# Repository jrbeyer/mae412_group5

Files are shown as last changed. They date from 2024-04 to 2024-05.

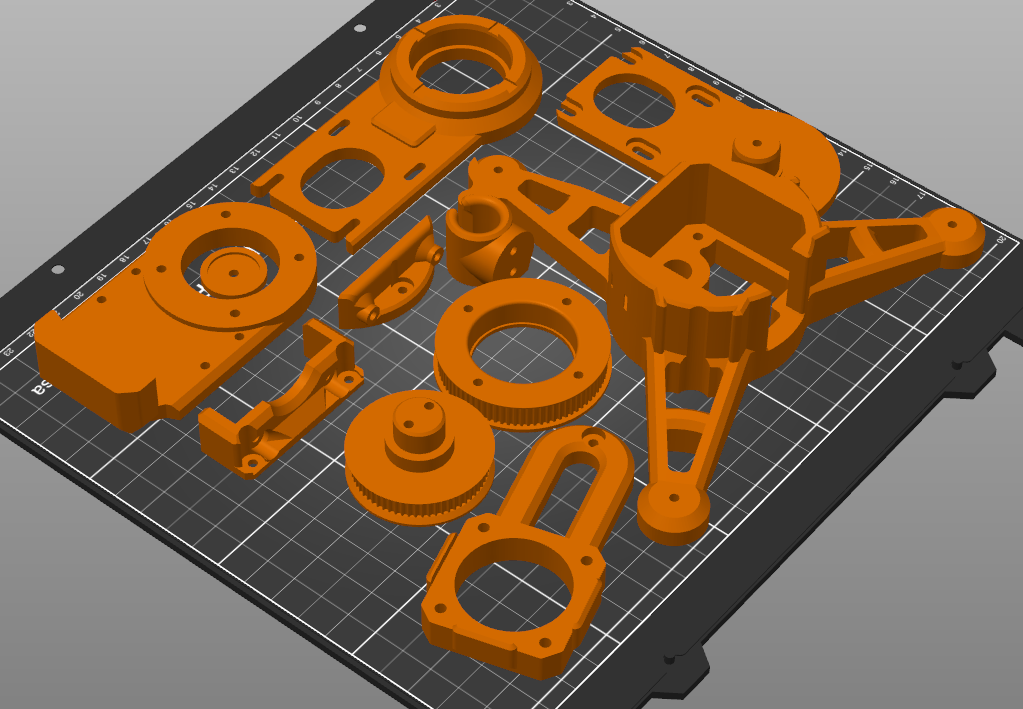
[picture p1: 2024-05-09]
Pan_Tilt_CAD/images/How_to_print_everything_Laser_pointer_robot.png

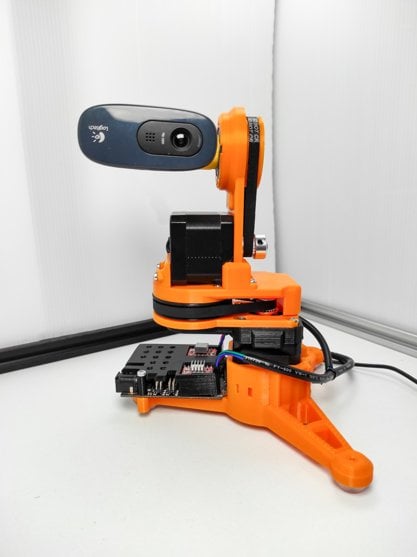
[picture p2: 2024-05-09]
Pan_Tilt_CAD/images/remotely_operated_webcam.jpg

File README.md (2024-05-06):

# Custom Model Train System With Pan-Tilt Tracking, Positioning, and Aiming Sentries

This repository contains the codebase for a custom model train system control. The system uses two pan-tilt turrets, one for searching and tracking a train as it follows a track, and the other for hitting the train with a laser from any region of the track.

## System Overview

The system is designed around two custom 3D printed pan-tilt turrets, each equipped with a NEMA 17 stepper motor, variable current motor drivers, and AS5600 motor encoders. The turrets use specific ratio gear pulleys for precise control.

The train system is controlled by a Hornbee train controller system and a custom microprocessor implemented on a scotchflex vector board consisting of an EEPROM, ACIA, and other components. The system interfaces with two ESP32-S2-Minis and custom power sensor fusion and motor control boards.

## Features

- **Train Tracking**: Uses a PixyCam and a Time-of-Flight (ToF) sensor to search and track the train. The system outputs the global coordinates of the train via ESP32.
- **Laser Control**: Takes in the reported coordinates of the train and controls a laser to hit the train from any region of the track.

## Hardware Requirements

- ESP32-S2-Minis
- PixyCam
- Time-of-Flight (ToF) sensor
- Pan-Tilt Turrets (Custom 3D printed)
- NEMA 17 Stepper Motors
- Variable Current Motor Drivers
- AS5600 Motor Encoders
- Specific Ratio Gear Pulleys
- Laser Pointer
- Hornbee Train Controller System
- Custom Microprocessor (Implemented on a Scotchflex Vector Board)
- Custom Power Sensor Fusion and Motor Control Boards

## Software Requirements

- Arduino IDE
- VL53L0X Library
- Pixy Library
- BasicStepperDriver Library

## Setup

1. Connect the PixyCam and ToF sensor to the ESP32.
2. Connect the pan-tilt turrets to the ESP32.
3. Connect the laser pointer to the ESP32.
4. Open the `mae412_group5.ino` file in the Arduino IDE.
5. Upload the code to the ESP32.

## Usage

The system operates in three states:

- **Inactive**: The system is idle and the steppers are disabled.
- **Search**: The system searches for the train using the PixyCam and ToF sensor. The steppers are enabled and move the turret to track the train.
- **Lock**: The system locks onto the train and the laser pointer is activated. The turret moves to follow the train and the laser pointer adjusts to hit the train.

## Contributing

Pull requests are welcome. For major changes, please open an issue first to discuss what you would like to change.

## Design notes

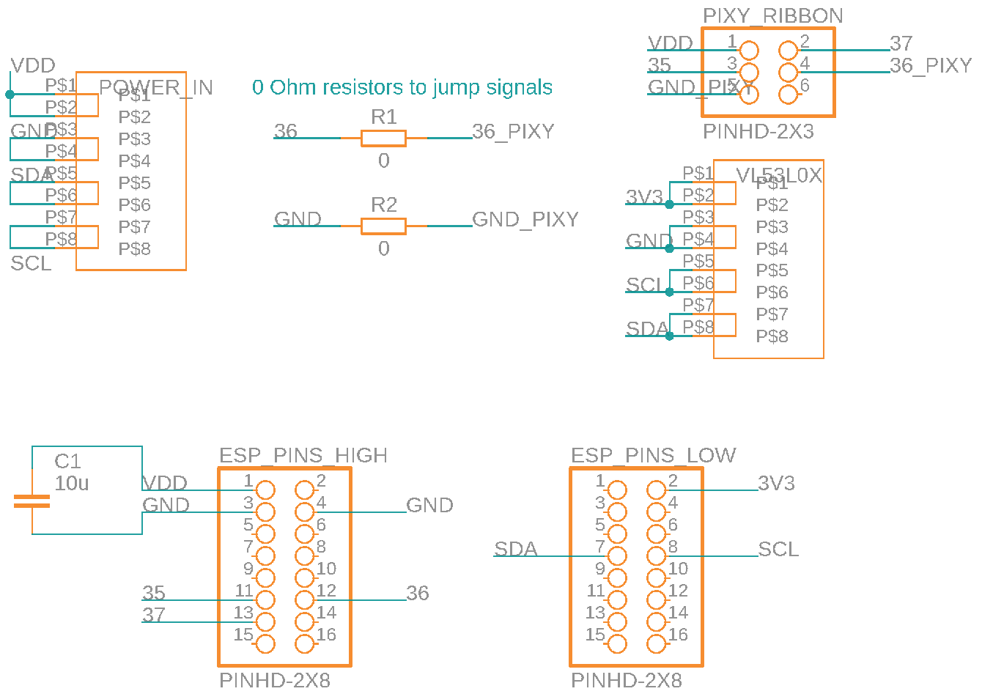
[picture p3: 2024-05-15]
PCB_CAD/pixy ESP daughter board schematic.png

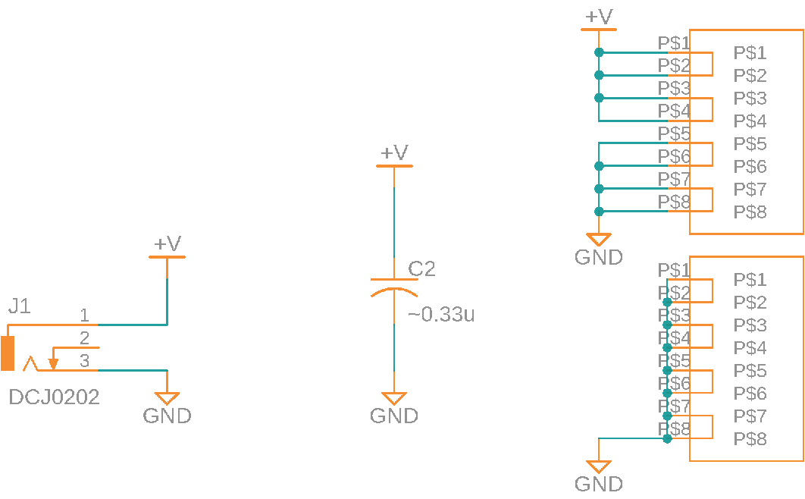
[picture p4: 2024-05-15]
PCB_CAD/12v_power_supply_schematic.png

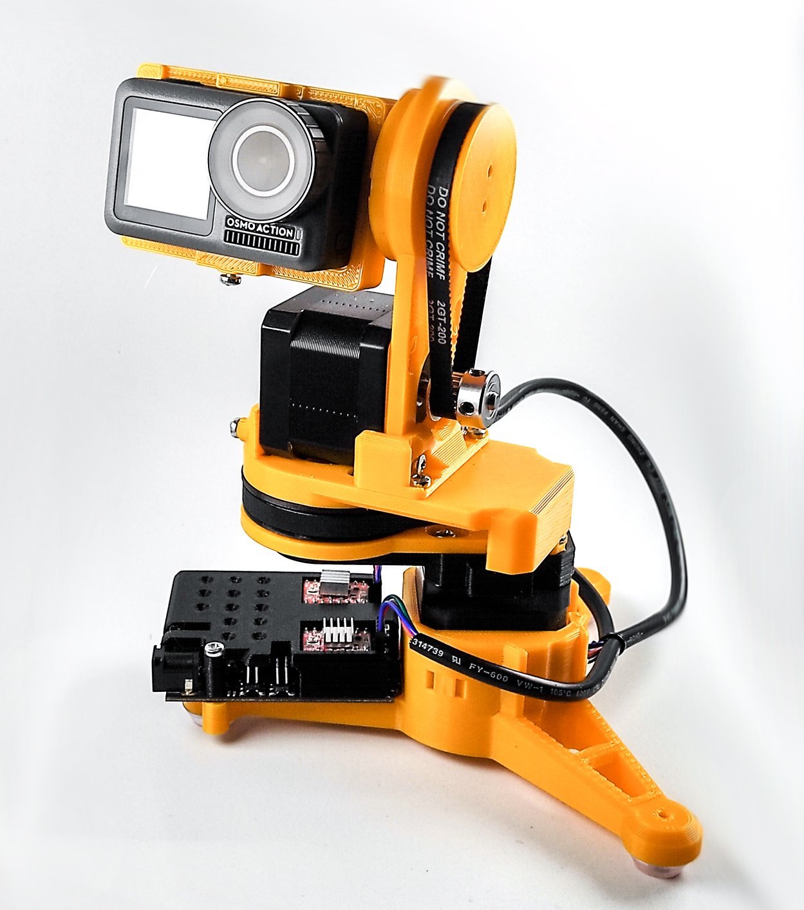
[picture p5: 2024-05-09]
Pan_Tilt_CAD/images/CAMERA-GIMBAL-with-NEMA17-motors_v2.jpg

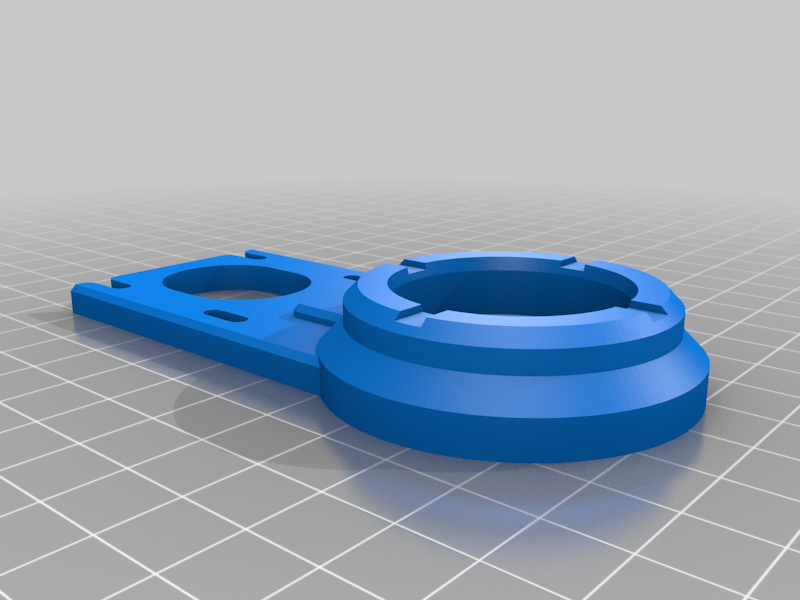
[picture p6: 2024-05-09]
Pan_Tilt_CAD/images/UPPER_ARM_VERTICAL_SUPPORT_V10.png

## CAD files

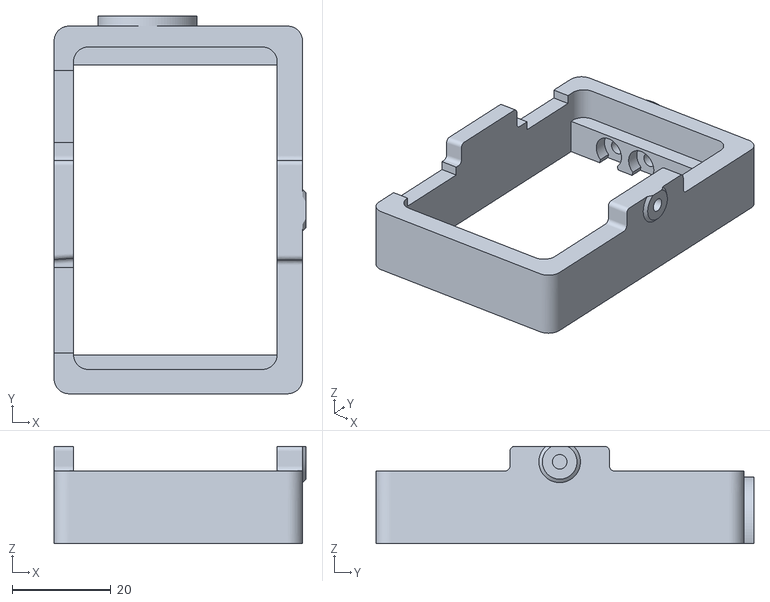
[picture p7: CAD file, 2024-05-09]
Pan_Tilt_CAD/files/DJI_OSMO_ACTION_CAMERA_HOLDER_V2.stl
50.9 x 76.3 x 19.7

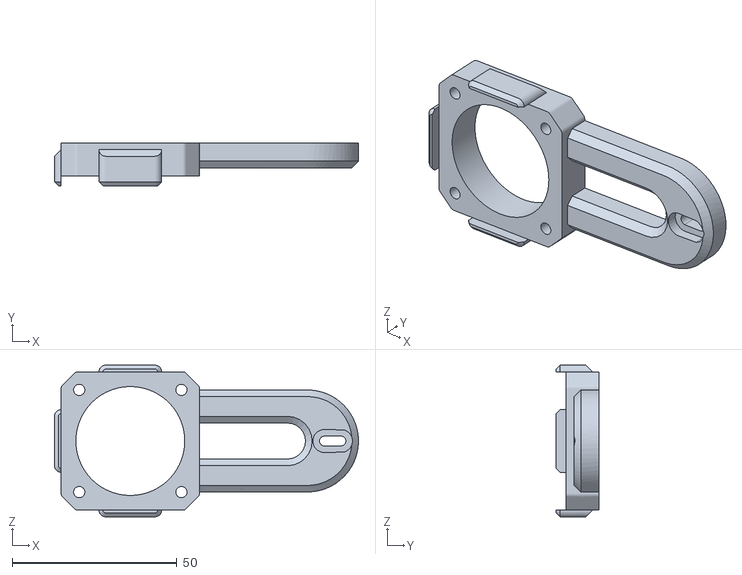
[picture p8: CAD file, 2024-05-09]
Pan_Tilt_CAD/files/LOWER_ARM_V11_by_mikeq.stl
92.2 x 13.0 x 46.0

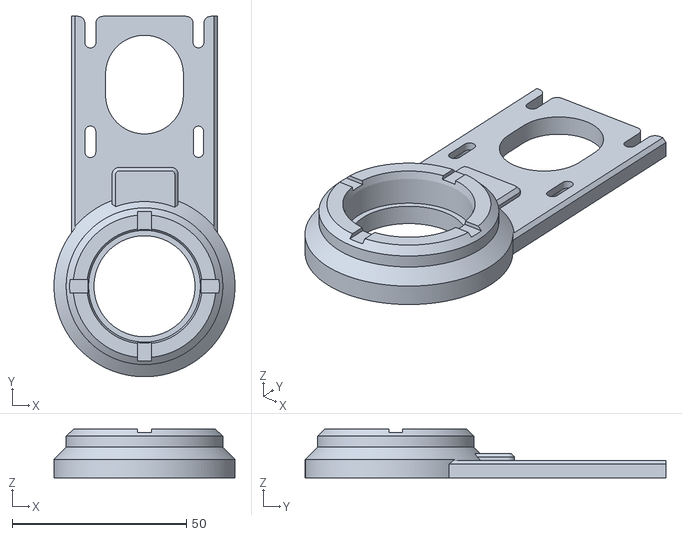
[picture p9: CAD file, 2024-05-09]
Pan_Tilt_CAD/files/UPPER_ARM_VERTICAL_SUPPORT_V10.stl
52.0 x 103.6 x 14.0

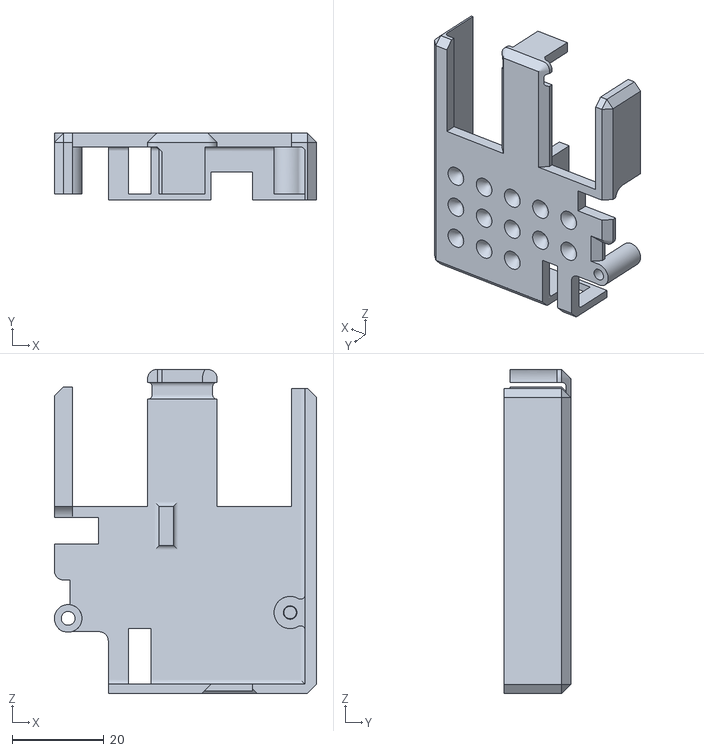
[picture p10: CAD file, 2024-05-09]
Pan_Tilt_CAD/files/DEVIA_board_3D_mode_CASE.stl
57.0 x 14.5 x 70.4

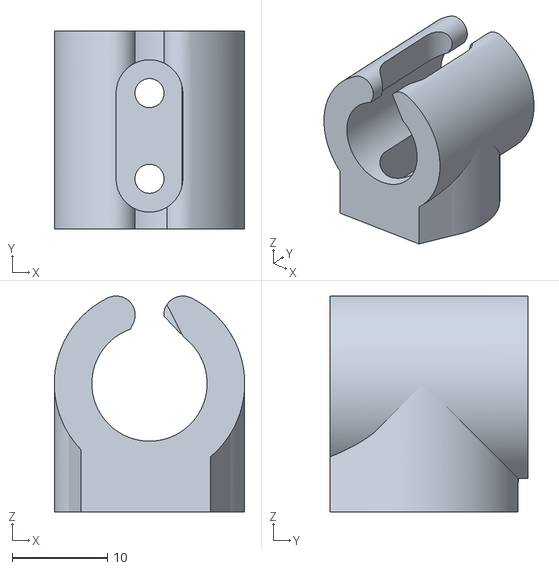
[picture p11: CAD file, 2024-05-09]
Pan_Tilt_CAD/files/TORCH-LASER_SUPPORT_12mm.stl
20.0 x 20.8 x 22.7

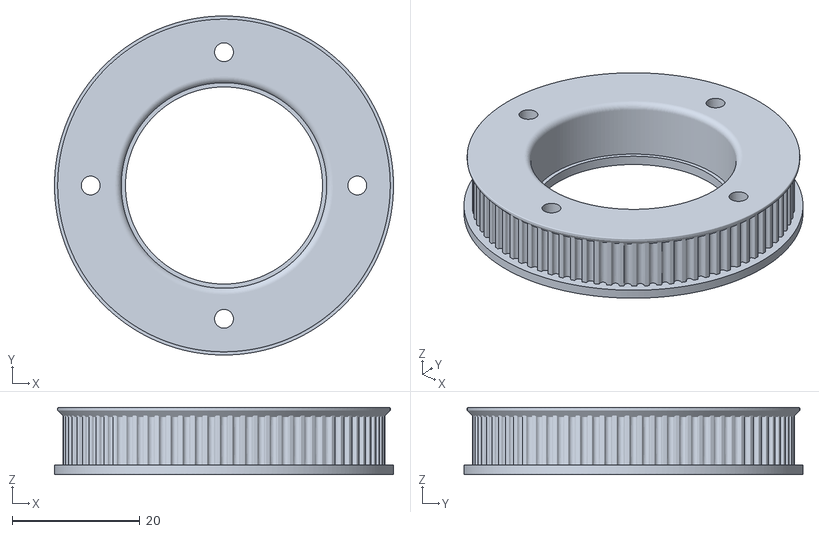
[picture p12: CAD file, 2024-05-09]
Pan_Tilt_CAD/files/PULLEY_80_V10.stl
53.0 x 53.0 x 10.5

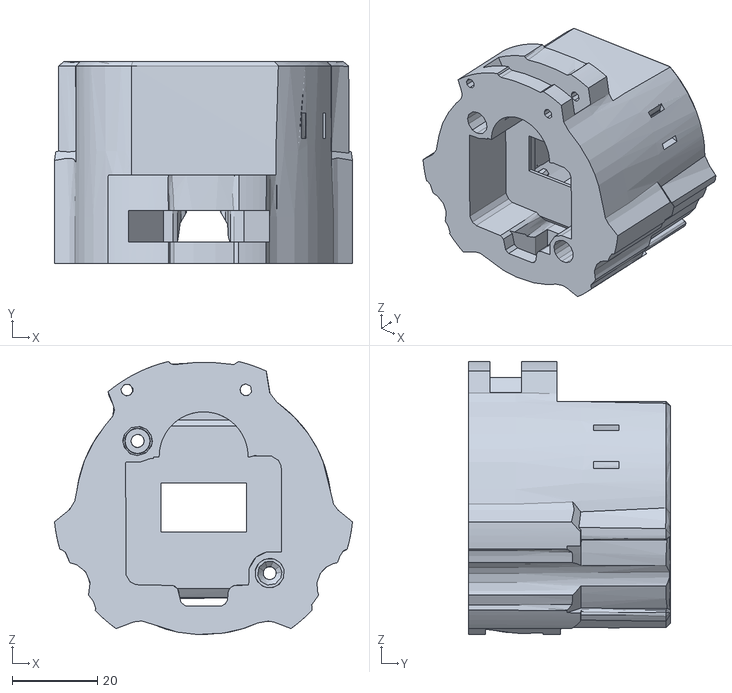
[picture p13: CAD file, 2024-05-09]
Pan_Tilt_CAD/files/bottom_encoder v4.stl
69.9 x 47.3 x 64.1

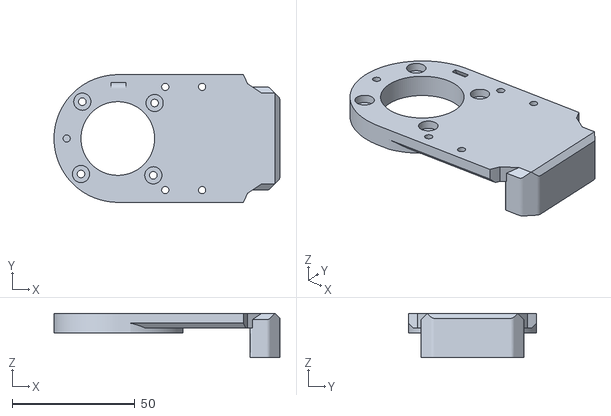
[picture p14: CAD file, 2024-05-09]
Pan_Tilt_CAD/files/UPPER_ARM_V10.stl
92.1 x 52.0 x 18.0

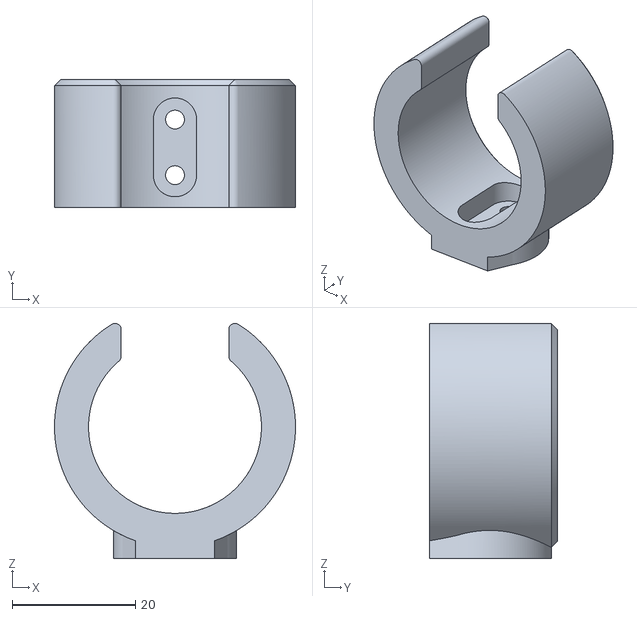
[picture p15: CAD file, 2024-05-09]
Pan_Tilt_CAD/files/FLASHLIGHT_HOLDER_28mm.stl
39.0 x 20.8 x 38.1

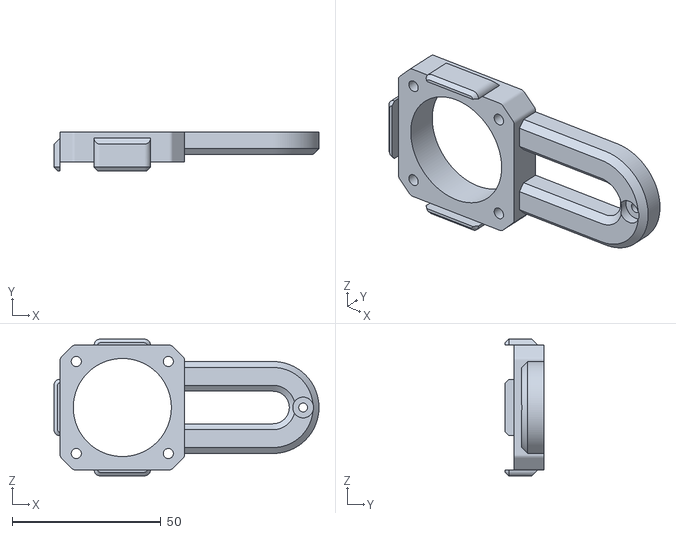
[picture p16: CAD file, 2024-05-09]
Pan_Tilt_CAD/files/LOWER_ARM_V10.stl
89.2 x 13.0 x 46.0

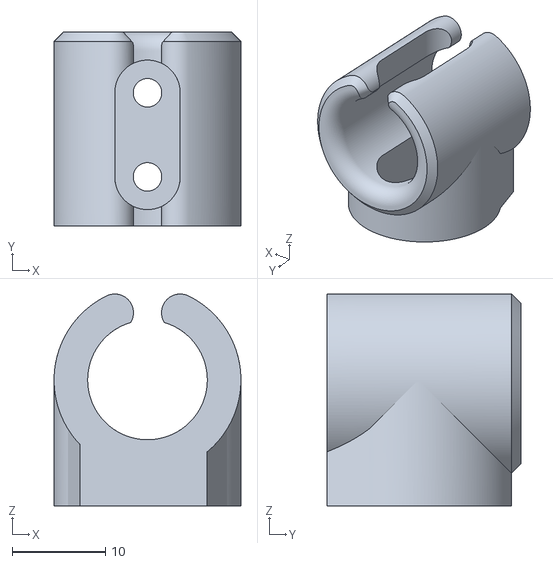
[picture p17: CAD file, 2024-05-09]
Pan_Tilt_CAD/files/TORCH-LASER_SUPPORT__6.4mm_V10.stl
20.0 x 20.8 x 22.7

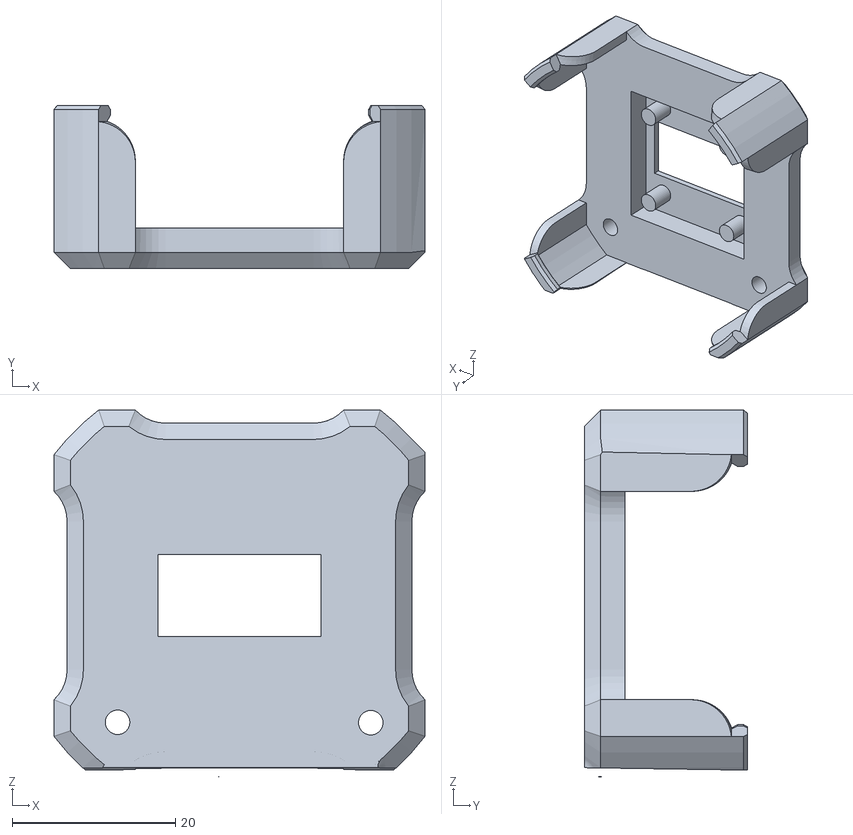
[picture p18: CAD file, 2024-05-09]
Pan_Tilt_CAD/files/top_encoder v2.stl
45.4 x 20.0 x 44.9

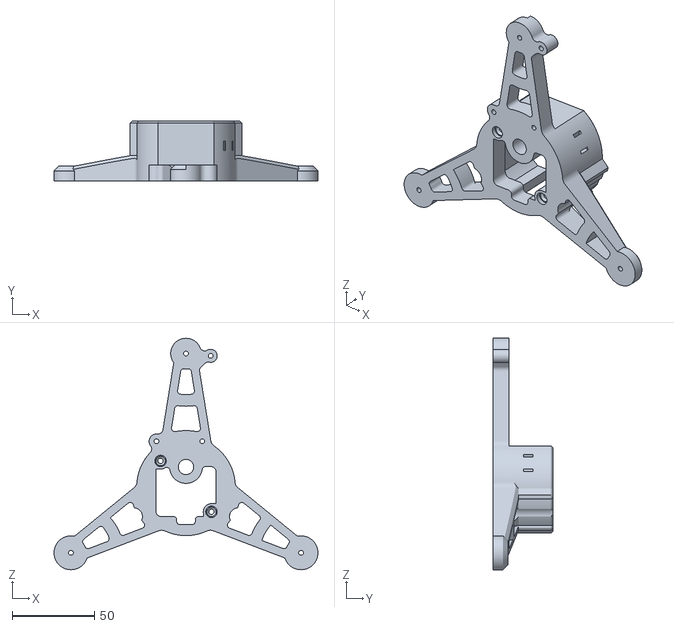
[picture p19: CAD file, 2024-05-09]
Pan_Tilt_CAD/files/BASE_V10.stl
160.8 x 36.3 x 141.1

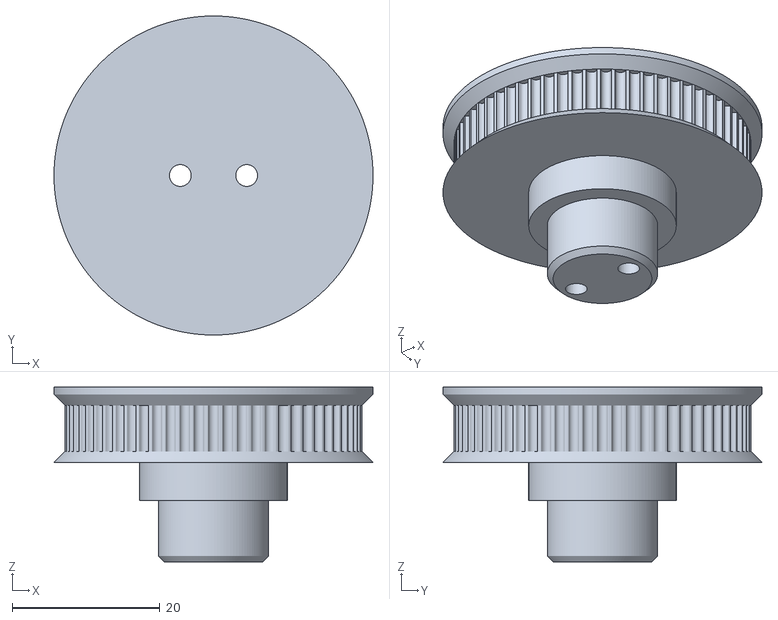
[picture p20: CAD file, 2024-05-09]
Pan_Tilt_CAD/files/PULLEY_60_V10.stl
43.2 x 43.2 x 23.7

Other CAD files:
Pan_Tilt_CAD/files/TORCH-LASER_SUPPORT_14mm.stl
Pan_Tilt_CAD/files/LOWER_ARM_PULLEY_SUPPORT_V10.stl
Pan_Tilt_CAD/files/CAP_V10.stl
Pan_Tilt_CAD/files/UPPER_ARM_MOTOR_HOLDER_RIGHT_V10.stl
Pan_Tilt_CAD/files/UPPER_ARM_MOTOR_HOLDER_LEFT_V10.stl
Pan_Tilt_CAD/files/bottom_encoder v2.stl
Pan_Tilt_CAD/files/pixycam_rangefinder_mount v2.stl
Pan_Tilt_CAD/files/pixycam_rangefinder_mount v3.stl
Pan_Tilt_CAD/files/pixycam_rangefinder_mount v4.stl

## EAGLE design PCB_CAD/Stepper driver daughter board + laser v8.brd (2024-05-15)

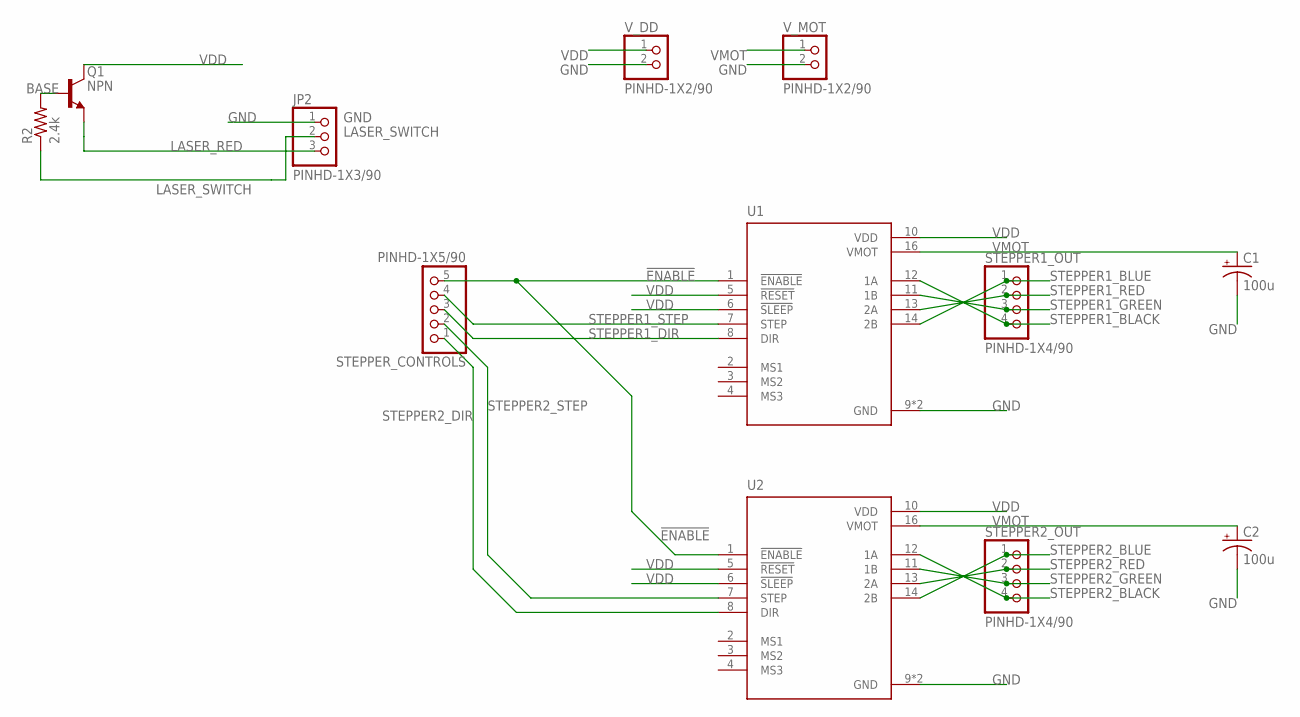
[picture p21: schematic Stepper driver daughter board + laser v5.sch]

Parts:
C1, C2: 100u; E22-6
JP2: PINHD-1X3/90; 1X03/90
Q1: NPN; TO92
R2: 2.4k; 0207/10
STEPPER1_OUT, STEPPER2_OUT: PINHD-1X4/90; 1X04/90
STEPPER_CONTROLS: PINHD-1X5/90; 1X05/90
U1, U2: A4988_STEPPER_MOTOR_DRIVER_CARRIER; MODULE_A4988_STEPPER_MOTOR_DRIVER_CARRIER
V_DD: PINHD-1X2/90; 1X02/90
V_MOT: PINHD-1X2/90; 1X02/90

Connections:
!ENABLE: STEPPER_CONTROLS.5, U1.1 (!ENABLE), U2.1 (!ENABLE)
BASE: Q1.2 (B), R2.2
GND: C1.-, C2.-, JP2.1, U1.9 (GND), U1.15 (GND), U2.9 (GND), U2.15 (GND), V_DD.2, V_MOT.2
LASER_RED: JP2.3, Q1.1 (E)
LASER_SWITCH: JP2.2, R2.1
STEPPER1_BLACK: STEPPER1_OUT.4, U1.12 (1A)
STEPPER1_BLUE: STEPPER1_OUT.1, U1.14 (2B)
STEPPER1_DIR: STEPPER_CONTROLS.3, U1.8 (DIR)
STEPPER1_GREEN: STEPPER1_OUT.3, U1.11 (1B)
STEPPER1_RED: STEPPER1_OUT.2, U1.13 (2A)
STEPPER1_STEP: STEPPER_CONTROLS.4, U1.7 (STEP)
STEPPER2_BLACK: STEPPER2_OUT.4, U2.12 (1A)
STEPPER2_BLUE: STEPPER2_OUT.1, U2.14 (2B)
STEPPER2_DIR: STEPPER_CONTROLS.1, U2.8 (DIR)
STEPPER2_GREEN: STEPPER2_OUT.3, U2.11 (1B)
STEPPER2_RED: STEPPER2_OUT.2, U2.13 (2A)
STEPPER2_STEP: STEPPER_CONTROLS.2, U2.7 (STEP)
VDD: Q1.3 (C), U1.5 (!RESET), U1.6 (!SLEEP), U1.10 (VDD), U2.5 (!RESET), U2.6 (!SLEEP), U2.10 (VDD), V_DD.1
VMOT: C1.+, C2.+, U1.16 (VMOT), U2.16 (VMOT), V_MOT.1

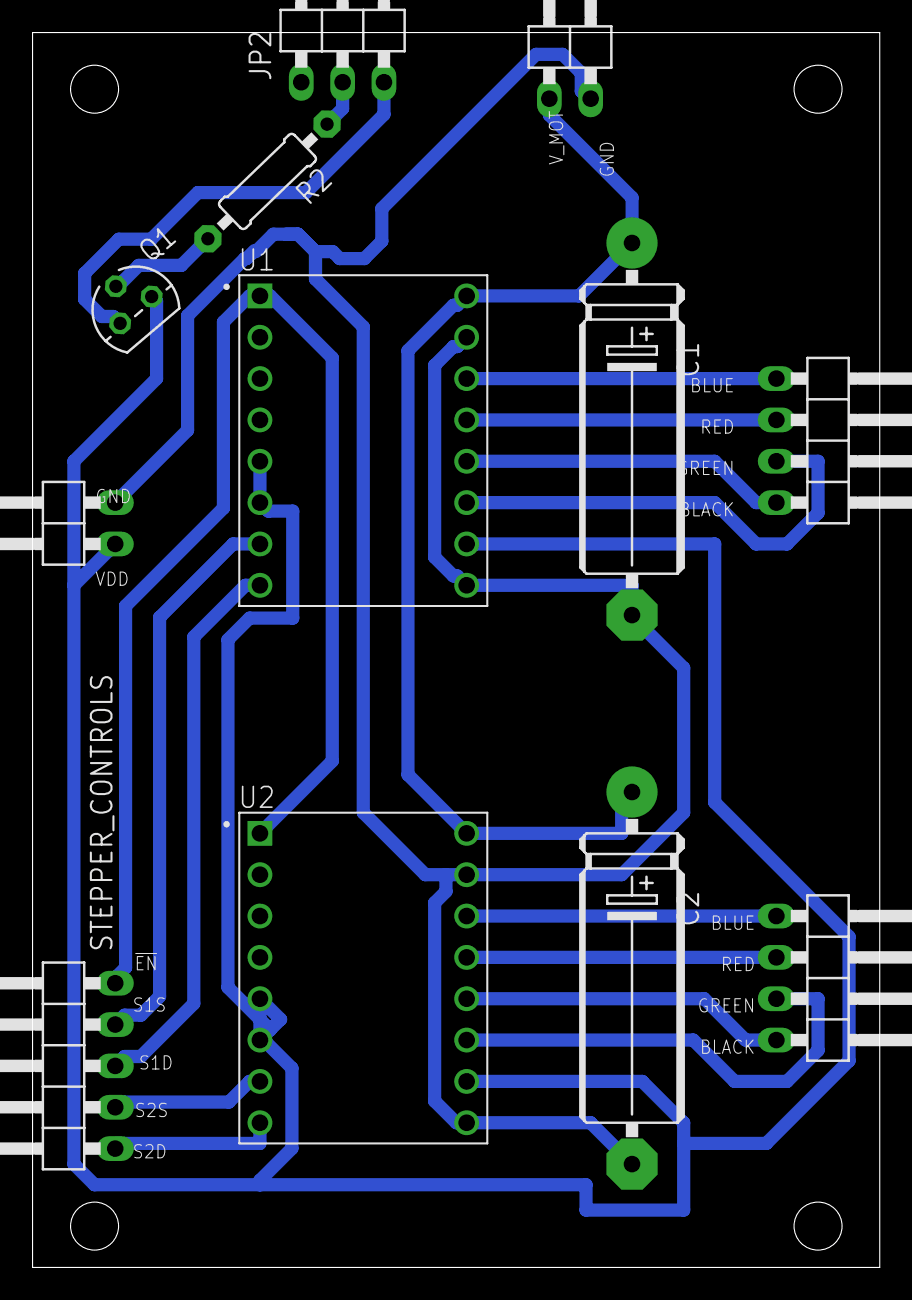
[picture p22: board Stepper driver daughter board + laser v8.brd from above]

Board: 2 copper layers, 52.0 x 75.9 mm, 12 parts (0 on the bottom side), 19 nets.

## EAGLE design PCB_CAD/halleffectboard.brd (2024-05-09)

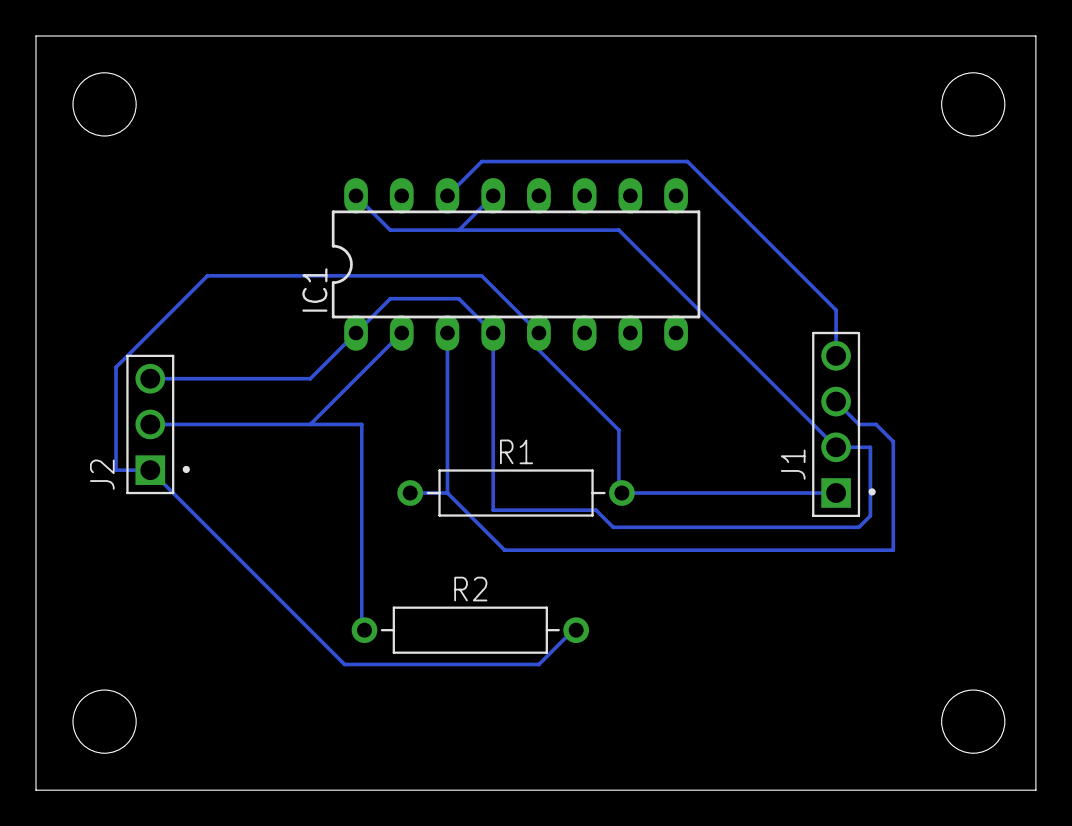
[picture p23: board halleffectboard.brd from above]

Board: 2 copper layers, 55.5 x 41.9 mm, 5 parts (0 on the bottom side), 5 nets.

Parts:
IC1: 7476N; DIL16
J1: 61300411121
J2: 61300311121
R1, R2: RESAD1176W63L850D250B

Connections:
CLR: IC1.3, J1.3, R1.1
GND: IC1.1, IC1.4, IC1.13, IC1.16, J1.2, J2.3
HALL: IC1.2, J2.2, R2.1
OUT: IC1.14, J1.4
VCC: IC1.5, J1.1, J2.1, R1.2, R2.2

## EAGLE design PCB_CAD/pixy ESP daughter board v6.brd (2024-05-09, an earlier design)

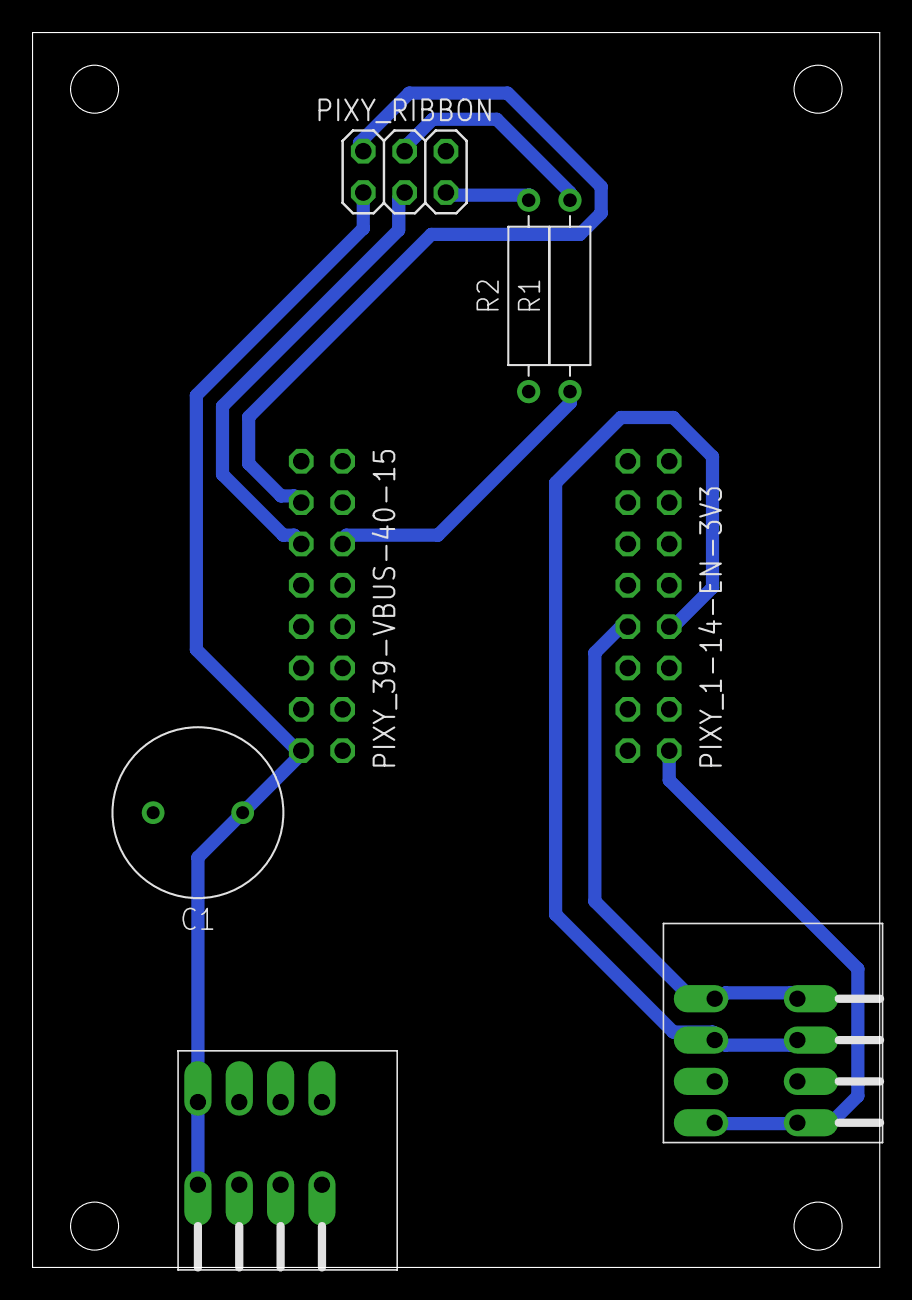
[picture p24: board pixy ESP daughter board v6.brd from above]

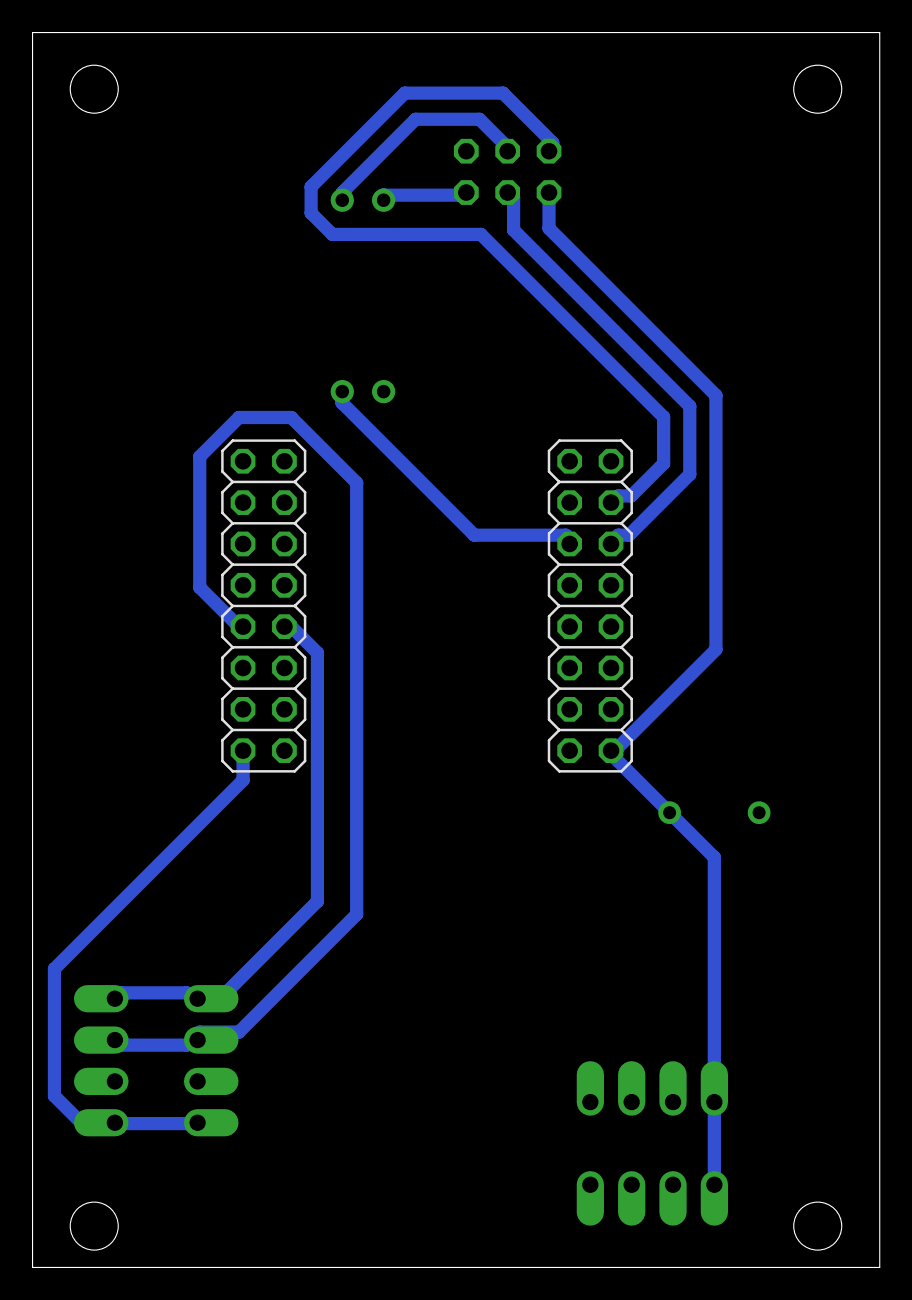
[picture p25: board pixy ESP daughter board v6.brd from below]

Board: 2 copper layers, 52.0 x 75.9 mm, 8 parts (2 on the bottom side), 10 nets.

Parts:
C1: 10u; CAPRD550W60D1025H1250B
PIXY_1-14-EN-3V3, PIXY_39-VBUS-40-15: PINHD-2X8; 2X08
PIXY_RIBBON: PINHD-2X3; 2X03
POWER_IN: TE_CONN_1-2834016-4; 1-2834016-4
R1, R2: 0; RESAD1176W63L850D250B
VL53L0X1: TE_CONN_1-2834016-4; 1-2834016-4

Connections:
3V3: PIXY_1-14-EN-3V3.2, VL53L0X1.P$1, VL53L0X1.P$2
35: PIXY_39-VBUS-40-15.11, PIXY_RIBBON.3
36: PIXY_39-VBUS-40-15.12, R1.1
36_PIXY: PIXY_RIBBON.4, R1.2
37: PIXY_39-VBUS-40-15.13, PIXY_RIBBON.2
GND: C1.2, PIXY_39-VBUS-40-15.3, PIXY_39-VBUS-40-15.4, POWER_IN.P$3, POWER_IN.P$4, POWER_IN.P$5, POWER_IN.P$6, POWER_IN.P$7, POWER_IN.P$8, R2.1, VL53L0X1.P$3, VL53L0X1.P$4
GND_PIXY: PIXY_RIBBON.5, R2.2
SCL: PIXY_1-14-EN-3V3.8, VL53L0X1.P$5, VL53L0X1.P$6
SDA: PIXY_1-14-EN-3V3.7, VL53L0X1.P$7, VL53L0X1.P$8
VDD: C1.1, PIXY_39-VBUS-40-15.1, PIXY_RIBBON.1, POWER_IN.P$1, POWER_IN.P$2

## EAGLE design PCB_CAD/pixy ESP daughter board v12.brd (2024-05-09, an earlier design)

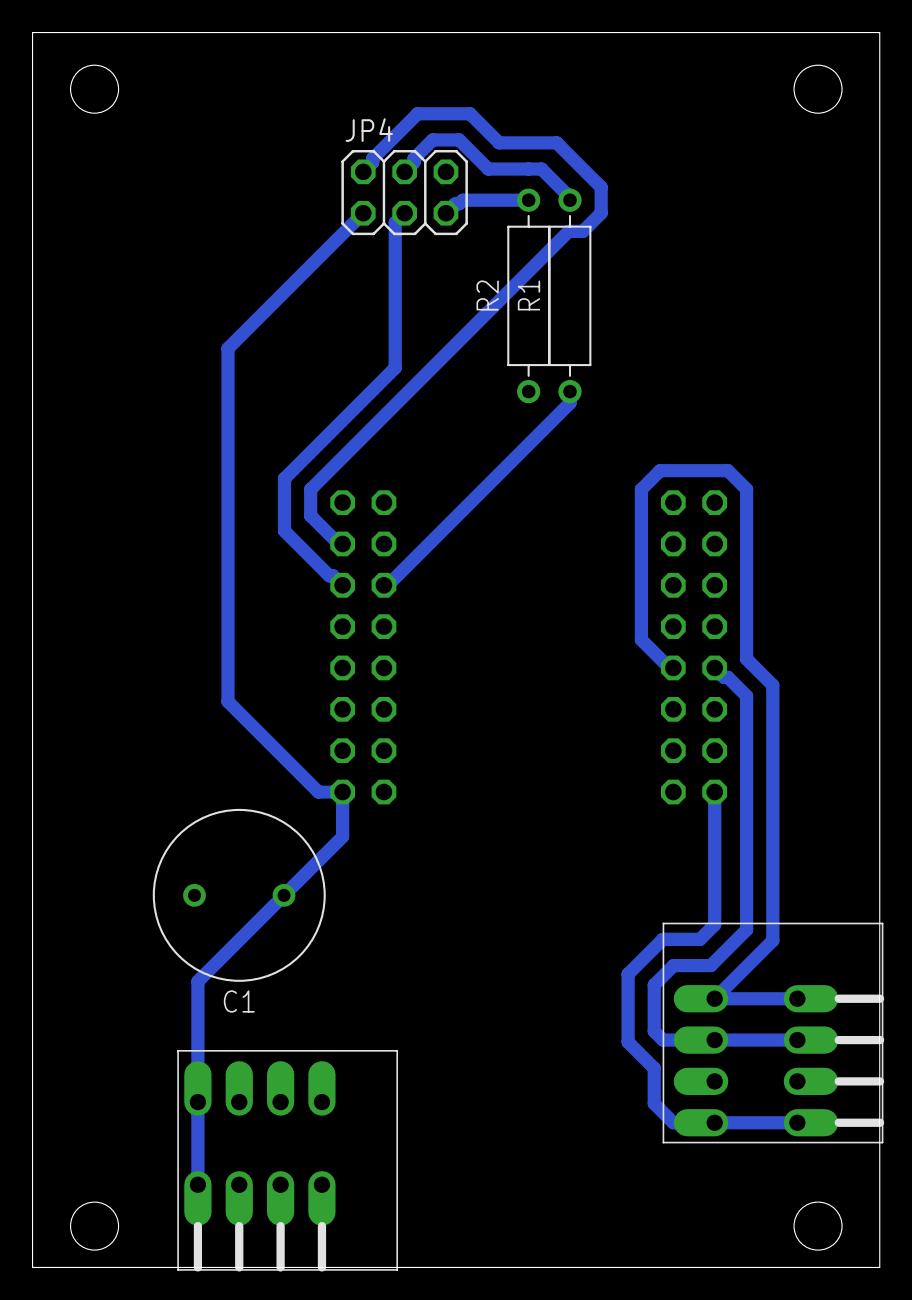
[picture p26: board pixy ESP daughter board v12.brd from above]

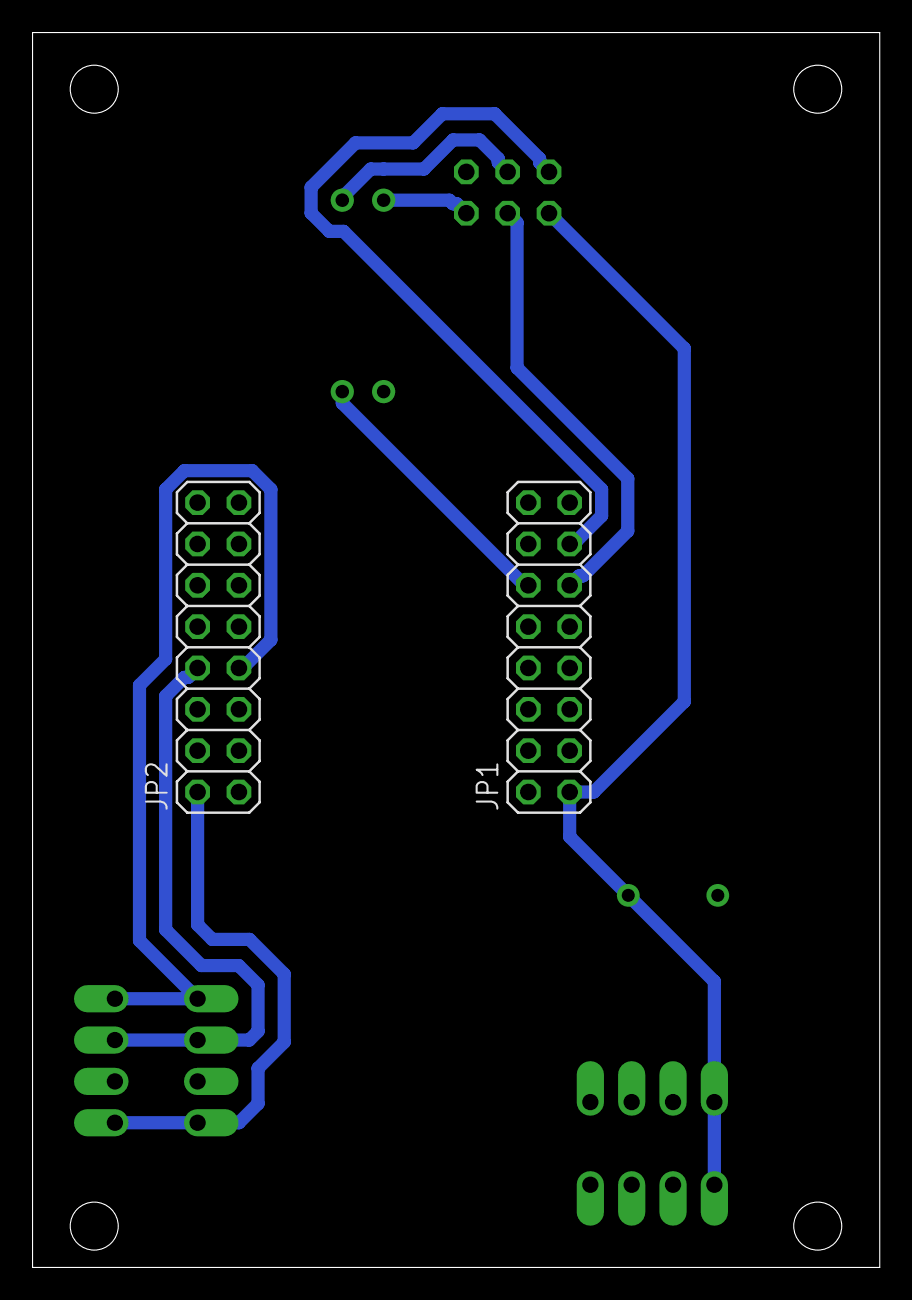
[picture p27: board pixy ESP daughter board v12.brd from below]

Board: 2 copper layers, 52.0 x 75.9 mm, 8 parts (2 on the bottom side), 10 nets.

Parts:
C1: 10u; CAPRD550W60D1025H1250B
JP1, JP2: PINHD-2X8; 2X08
JP4: PINHD-2X3; 2X03
POWER_IN: TE_CONN_1-2834016-4; 1-2834016-4
R1, R2: 0; RESAD1176W63L850D250B
VL53L0X1: TE_CONN_1-2834016-4; 1-2834016-4

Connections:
3V3: JP2.2, VL53L0X1.P$1, VL53L0X1.P$2
35: JP1.11, JP4.3
36: JP1.12, R1.1
36_PIXY: JP4.4, R1.2
37: JP1.13, JP4.2
GND: C1.2, JP1.3, JP1.4, POWER_IN.P$3, POWER_IN.P$4, POWER_IN.P$5, POWER_IN.P$6, POWER_IN.P$7, POWER_IN.P$8, R2.1, VL53L0X1.P$3, VL53L0X1.P$4
GND_PIXY: JP4.5, R2.2
SCL: JP2.8, VL53L0X1.P$5, VL53L0X1.P$6
SDA: JP2.7, VL53L0X1.P$7, VL53L0X1.P$8
VDD: C1.1, JP1.1, JP4.1, POWER_IN.P$1, POWER_IN.P$2

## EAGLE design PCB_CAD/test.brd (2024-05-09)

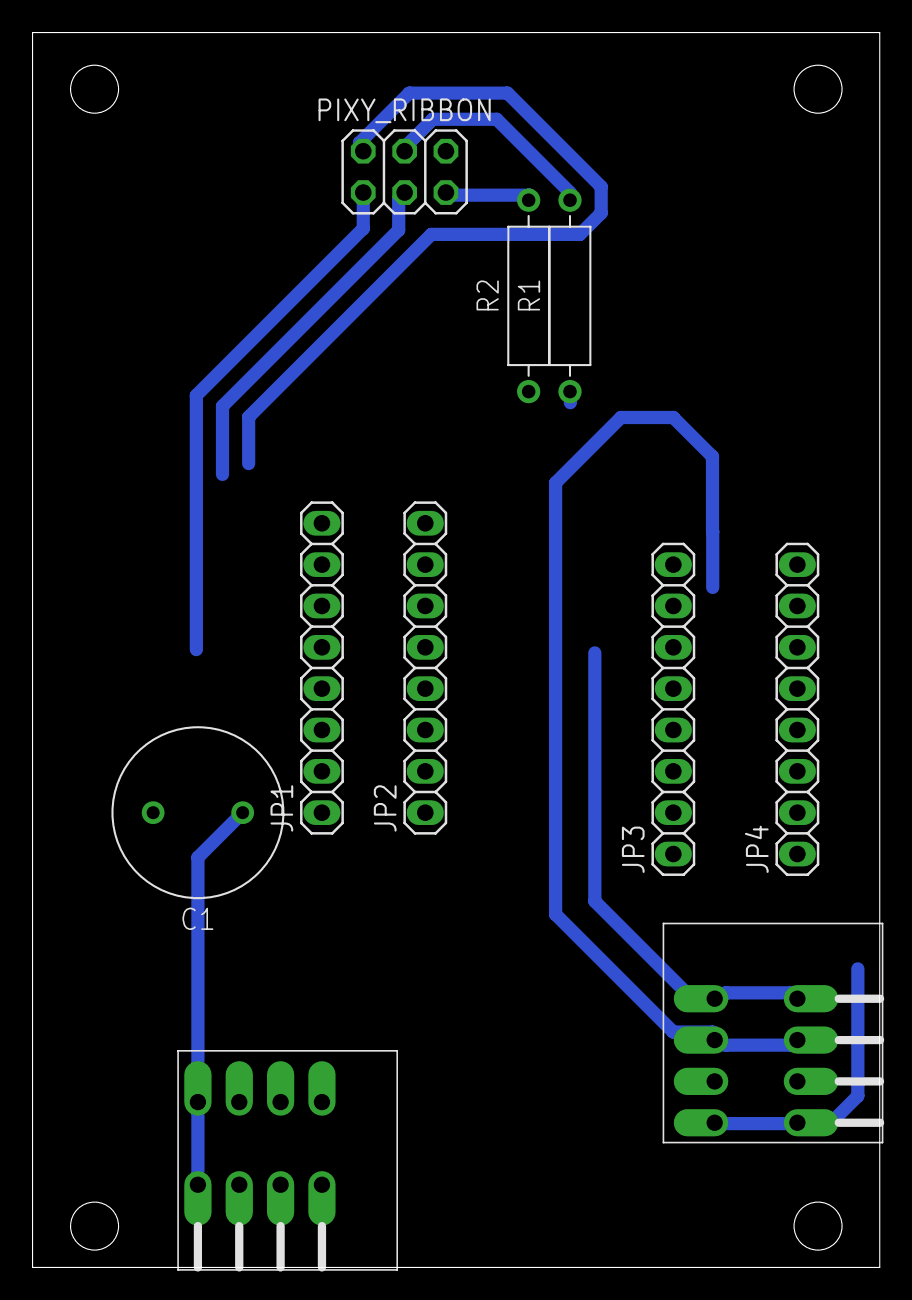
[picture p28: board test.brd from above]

Board: 2 copper layers, 52.0 x 75.9 mm, 10 parts (0 on the bottom side), 10 nets.

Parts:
C1: 10u; CAPRD550W60D1025H1250B
JP1, JP2, JP3, JP4: PINHD-1X8; 1X08
PIXY_RIBBON: PINHD-2X3; 2X03
POWER_IN: TE_CONN_1-2834016-4; 1-2834016-4
R1, R2: 0; RESAD1176W63L850D250B
VL53L0X1: TE_CONN_1-2834016-4; 1-2834016-4

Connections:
3V3: JP4.1, VL53L0X1.P$1, VL53L0X1.P$2
35: JP1.6, PIXY_RIBBON.3
36: JP2.6, R1.1
36_PIXY: PIXY_RIBBON.4, R1.2
37: JP1.7, PIXY_RIBBON.2
GND: C1.2, JP1.2, JP2.2, POWER_IN.P$3, POWER_IN.P$4, POWER_IN.P$5, POWER_IN.P$6, POWER_IN.P$7, POWER_IN.P$8, R2.1, VL53L0X1.P$3, VL53L0X1.P$4
GND_PIXY: PIXY_RIBBON.5, R2.2
SCL: JP4.4, VL53L0X1.P$5, VL53L0X1.P$6
SDA: JP3.4, VL53L0X1.P$7, VL53L0X1.P$8
VDD: C1.1, JP1.1, PIXY_RIBBON.1, POWER_IN.P$1, POWER_IN.P$2

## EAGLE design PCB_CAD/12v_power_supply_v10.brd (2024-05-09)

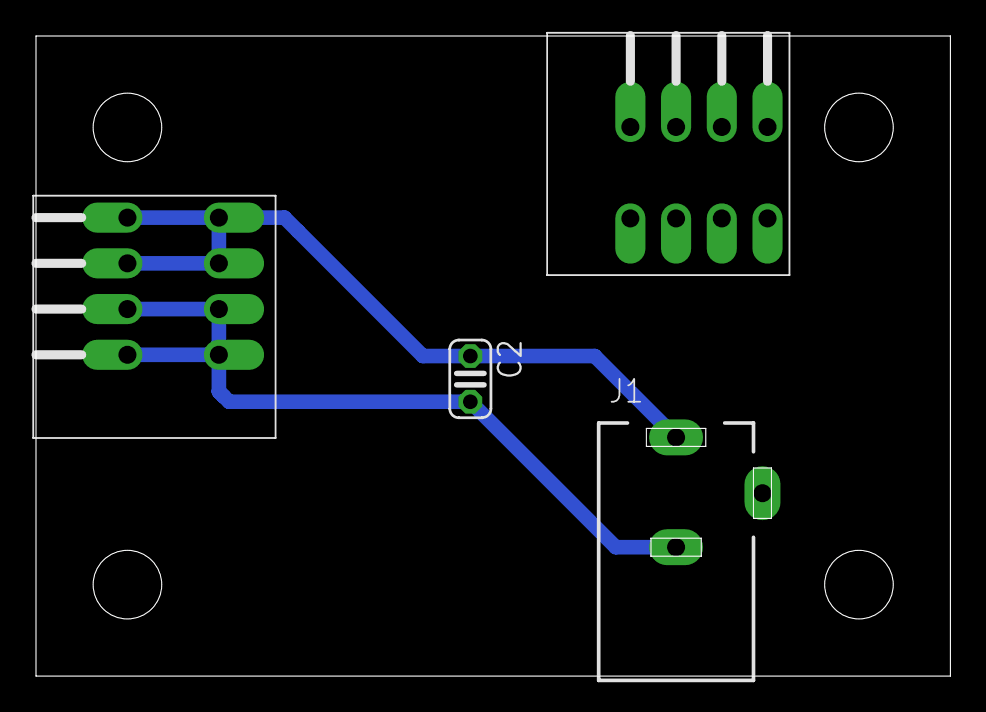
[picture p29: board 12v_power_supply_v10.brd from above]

Board: 2 copper layers, 50.8 x 35.6 mm, 4 parts (0 on the bottom side), 2 nets.

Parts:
C2: ~0.33u; C025-024X044
J1: DCJ0202
U$1, U$2: TE_CONN_1-2834016-4; 1-2834016-4

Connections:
+V: C2.1, J1.1, U$1.P$1, U$1.P$2, U$1.P$3, U$1.P$4
GND: C2.2, J1.3, U$1.P$5, U$1.P$6, U$1.P$7, U$1.P$8, U$2.P$1, U$2.P$2, U$2.P$3, U$2.P$4, U$2.P$5, U$2.P$6, U$2.P$7, U$2.P$8

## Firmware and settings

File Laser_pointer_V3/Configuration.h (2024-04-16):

// 2 Axis robot project 
// JJROBOTS

#include <stdint.h>
#include <math.h>

#define ROBOT_ABSOLUTE_MAX_M1 121 //121 //114 //121   // max degrees
#define ROBOT_ABSOLUTE_MAX_M2 142 //146 //146 //142   // max degress

#define MICROSTEPPING 16
#define MOTOR_STEPS 200 //1.8 degree motor = 360/1.8=200

#define M1_REDUCTION 4
#define M2_REDUCTION 3.2

// This depends on your motor type and reduction
#define M1_AXIS_STEPS_PER_UNIT (((MOTOR_STEPS*MICROSTEPPING)/360.0)*M1_REDUCTION)
#define M2_AXIS_STEPS_PER_UNIT (((MOTOR_STEPS*MICROSTEPPING)/360.0)*M2_REDUCTION)

// Maximun motor acceleration in (steps/seg2)/1000 [acceleration in miliseconds] 30 => 30.000 steps/sec2
#define MAX_ACCEL_M1 30  //50
#define MAX_ACCEL_M2 30  //50 

#define MIN_ACCEL_M1 50
#define MIN_ACCEL_M2 50

// Maximun speed in steps/seg (max 32765)
#define MAX_SPEED_M1 16000 //16000
#define MAX_SPEED_M2 16000 //16000

#define MIN_SPEED_M1 200  //1000
#define MIN_SPEED_M2 200  //1000

// Servo definitions
// Servo1:
#define SERVO1_NEUTRAL 1500  // Servo neutral position Gripped angle
#define SERVO1_MIN_PULSEWIDTH 900
#define SERVO1_MAX_PULSEWIDTH 2100
#define SERVO1_RANGE (SERVO1_MAX_PULSEWIDTH-SERVO1_MIN_PULSEWIDTH)

// Servo2: 
#define SERVO2_NEUTRAL 1500  // Servo neutral position
#define SERVO2_MIN_PULSEWIDTH 900
#define SERVO2_MAX_PULSEWIDTH 2100
#define SERVO2_RANGE (SERVO2_MAX_PULSEWIDTH-SERVO2_MIN_PULSEWIDTH)

#define SERVO_SPEED 3

// UNCOMMENT THIS LINES TO INVERT MOTORS (by default 1)
//#define INVERT_M1_AXIS 1
//#define INVERT_M2_AXIS 1

// Robot
#define ROBOT_MIN_A1 -3600.0
#define ROBOT_MIN_A2 -360.0
#define ROBOT_MAX_A1 360.0
#define ROBOT_MAX_A2 360.0


// Initial robot position in angle/mm
// The robot must be set at this position at start time (steps initialization)
#define ROBOT_INITIAL_POSITION_M1 0
#define ROBOT_INITIAL_POSITION_M2 0

#define TELEMETRY "192.168.4.2"

#define MINIMUN_TIMER_PERIOD 32000 // For timer counters 

#define MSGMAXLEN 20  // Max message length. Message from the APP (parameters)
#define NODATA -20000

#define STOP_TOLERANCE 5  // Tolerance to check if the robot arrive at point

#define RAD2GRAD 57.2957795
#define GRAD2RAD 0.01745329251994329576923690768489

#define GREEN_LED A1
#define RED_LED A2
#define SWITCH_IN 30

// Structure definition
struct angles {
  float A1;
  float A2;
};


// Variable definitions

// Log and Timer variables
long loop_counter;
int16_t slow_loop_counter;
long timeout_counter;
long wait_counter;
int16_t timestamp=0;
int dt;
long timer_old;
long timer_value;
long slow_timer_old;
long slow_timer_value;
long laser_timer_old;
long laser_timer_value;
int debug_counter;
bool enable_udp_output = false;

// kinematic variables
// position, speed and acceleration are in step units
volatile int16_t position_M1;  // This variables are modified inside the Timer interrupts
volatile int16_t position_M2;
bool working = false;
bool M1stopping = false;
bool M2stopping = false;

int8_t dir_M1;     //(dir=1 positive, dir=-1 negative)
int8_t dir_M2;
float target_angleA1;
float target_angleA2;
int16_t target_position_M1;
int16_t target_position_M2;
int16_t diff_M1;
int16_t diff_M2;
int16_t speed_M1;   // Real motor speed (change dinamically during movements)
int16_t speed_M2;
int16_t config_speed_M1 = MAX_SPEED_M1;    // configured max speed
int16_t config_speed_M2 = MAX_SPEED_M2;
int16_t target_speed_M1 = config_speed_M1;       // target max speed for the actual movement                
int16_t target_speed_M2 = config_speed_M2;

int16_t acceleration_M1;    // Real motor acceleration
int16_t acceleration_M2;    // Real motor acceleration
int16_t config_acceleration_M1 = MAX_ACCEL_M1;   // Acceleration configuration
int16_t config_acceleration_M2 = MAX_ACCEL_M2;
float target_acceleration_M1 = MAX_ACCEL_M1;        // Acceleration for the actual movement
float target_acceleration_M2 = MAX_ACCEL_M2;

int16_t pos_stop_M1;
int16_t pos_stop_M2;
int16_t overshoot_compensation = 20;


int16_t actual_angleA1;
int16_t actual_angleA2;

long servo_counter;
int16_t servo_pos1;
int16_t servo_pos2;
bool servo1_ready = false;
bool servo2_ready = false;

int16_t iCH1;
int16_t iCH2;
int16_t iCH3;
int16_t iCH4;
int16_t iCH5;
int16_t iCH6;
int16_t iCH7;
int16_t iCH8;
uint8_t mode = 0;

uint8_t newMessage;
uint8_t MsgBuffer[MSGMAXLEN];

String MAC;


int16_t myAbs(int16_t param)
{
  if (param < 0)
    return -param;
  else
    return param;
}

long myAbsLong(long param)
{
  if (param < 0)
    return -param;
  else
    return param;
}

int sign(int val)
{
  if (val < 0)
    return (-1);
  else
    return (1);
}

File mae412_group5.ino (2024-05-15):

 /********************************************
 *  mae412_group5.ino
 *  Description: implements all functionality
 *  for Arduino-based two-stage targeting
 *  system.
 *
 *  Authors: Jacob Beyer, Vikash Modi, Jae Yoon
 *
 *
 ********************************************/

/********************************************
  Pin Defines
*********************************************/
 // Physical pin  | Arduino pin number    | Function

 // 27              A4 (ESP 8)              SDA (i2c)
 // 28              A5 (ESP 9)              SCL (i2c)
 // NOTE: no pin defines needed for this block (taken care of by libraries)

 // 1               ~                       RTS (for FTDI comms cable)
 // 2               0                       TxD/Orange (FTDI)
 // 3               1                       RxD/Yellow (FTDI)
 // 7,8                                     Vcc/GND
 // NOTE: no pin defines needed for this block

 //                 10                      Pixy stepper enable
 //                 11                      laser stepper enable
 //                 6,7                     track yaw dir,step
 //                 39,40                   track pitch dir,step
 //                 4,5                     target yaw dir,step
 //                 2,3                     target pitch dir,step
 //                 A0/14 (same pin)        laser diode on/off
 //                 16                      Kill switch
 #define P_motor_enable 10
 #define P_laser_motor_enable 11
 #define P_track_yaw_dir  6 
 #define P_track_yaw_step 7 
 #define P_track_pitch_dir  39
 #define P_track_pitch_step 40

 #define P_target_yaw_dir   4
 #define P_target_yaw_step  5
 #define P_target_pitch_dir   2
 #define P_target_pitch_step  3

 #define P_laser_on       14
 #define P_kill_switch    16

 #define PIN_LED 15
 
 
/********************************************
 Timer Things (mostly from docs)
*********************************************/
// DO NOT TOUCH
// These define's must be placed at the beginning before #include "TimerInterrupt.h" 
// _TIMERINTERRUPT_LOGLEVEL_ from 0 to 4 
// Don't define _TIMERINTERRUPT_LOGLEVEL_ > 0. Only for special ISR debugging only. Can hang the system. 
#define TIMER_INTERRUPT_DEBUG         0 
#define _TIMERINTERRUPT_LOGLEVEL_     0 
// To be included only in main(), .ino with setup() to avoid `Multiple Definitions` Linker Error 
#include "TimerInterrupt_Generic.h" 
// end DO NOT TOUCH

/********************************************
 Stepper driver things (mostly from docs)
*********************************************/
// Motor steps per revolution. Most steppers are 200 steps or 1.8 degrees/step
#define MOTOR_STEPS 200
#define RPM 100 
#define SLOW_RPM 100
// Since microstepping is set externally, make sure this matches the selected mode
// If it doesn't, the motor will move at a different RPM than chosen
// 1=full step, 2=half step etc.
#define MICROSTEPS 1


/********************************************
  Libraries
*********************************************/

#include <Wire.h> // I2C library
#include <I2C_16Bit.h>
#include <SPI.h>
#include <Pixy.h>
#include <VL53L0X.h>
#include "BasicStepperDriver.h"

#include <esp_now.h>
#include <WiFi.h>

#include "mae412_group5_defines.h"

/********************************************
  Typedefs
*********************************************/

typedef enum State {
  STATE_inactive,
  STATE_search,
  STATE_lock,
  STATE_num_state
};

typedef struct PID_params {
  double curr_target;   // the current desired position
  double curr_error;    // the current error 
  double kp;
  double ki;
  double kd;
  double integrator;      // integrates error over time
  double integrator_sat;
  double prior_error;
  double command_clip;
  long   count_est;       // estimate of how many counts the stepper has travelled
  long   count_clip;      // clip (keep pitch within [-36, 36]deg, keep yaw within [-720, 720]deg) (but in encoder counts)
};

/********************************************
  Global Variables
*********************************************/

// ESP NOW
// message passing
String success;
message_S inbound_message;
uint16_t wifi_watchdog;

// configure ESP NOW
esp_now_peer_info_t peerInfo;
// callback for data sent
// shouldn't be sending data
void OnDataSent(const uint8_t *mac_addr, esp_now_send_status_t status) {
  Serial.print("\r\nLast Packet Send Status:\t");
  Serial.println(status == ESP_NOW_SEND_SUCCESS ? "Delivery Success" : "Delivery Fail");
  if (status == 0){
    success = "Delivery Success :)";
  }
  else{
    success = "Delivery Fail :(";
  }
}
// Callback when data is received
void OnDataRecv(const uint8_t * mac, const uint8_t *incomingData, int len) {
  memcpy(&inbound_message, incomingData, sizeof(inbound_message));
  wifi_watchdog = 0;

  
    digitalWrite(PIN_LED, !digitalRead(PIN_LED));
  // Serial.print("Bytes received: ");
  // Serial.println(len);
  // if (inbound_message.pixy_saw_train) {
  //     Serial.println("Got train! clearing this flag...");
  //     inbound_message.pixy_saw_train = false;

  //     Serial.println("train_x: " + String(inbound_message.pixy_train_x));
  //     Serial.println("train_y: " + String(inbound_message.pixy_train_y));
  //   }
  //   if (inbound_message.rangefinder_got_range) {
  //     Serial.println("Got distance! clearing this flag...");
  //     inbound_message.rangefinder_got_range = false;

  //     Serial.println("distance (mm): " + String(inbound_message.rangefinder_range_mm));
  //   }
}


ESP32Timer ITimer1(1);

// counter
volatile uint16_t counter_80_hz = 0;             // counts 80Hz timer increments
volatile bool counter_new_val_available = false;  // asserted in timer ISR to tell loop that new counter is ready

// FSM signals
State control_state         = STATE_inactive; // state of control FSM
bool EXT_kill               = false;          // source: external switch, reset to STATE_inactive
bool VB_train_available     = false;          // source: vector board, asserted when valid train on tracks
bool PC_train_found         = false;          // source: pixycam, asserted whenever train is in line-of-sight of pixycam

uint16_t PC_train_watchdog  = 0;              // don't want FSM to change immediately in case of momentary glitch, so keep watchdog
uint16_t PC_train_watchdog_max = 10;          // but after 10 times in a row something's probably wrong, should search again

// PID elements
PID_params track_pitch_params;
PID_params track_yaw_params;
PID_params target_pitch_params;
PID_params target_yaw_params;

// External measurements
VL53L0X  rangefinder;
double   distance_train     = 0.0;  // mm
Pixy pixy;
double pixy_train_x         = 0;    // pixels, 0-319
double pixy_train_y         = 0;    // pixels, 0-199

// stepper motor controllers
BasicStepperDriver track_yaw(MOTOR_STEPS, P_track_yaw_dir, P_track_yaw_step, P_motor_enable);
BasicStepperDriver track_pitch(MOTOR_STEPS, P_track_pitch_dir, P_track_pitch_step, P_motor_enable);
BasicStepperDriver target_yaw(MOTOR_STEPS, P_target_yaw_dir, P_target_yaw_step, P_laser_motor_enable);
BasicStepperDriver target_pitch(MOTOR_STEPS, P_target_pitch_dir, P_target_pitch_step, P_laser_motor_enable);

bool steppers_enabled = false;  // keep track of if we have enabled or disabled the steppers
bool sweep_ccw = false;   // keep track of which direction we are sweeping in if true then ccw if false then cw

// computed values
double x_train = 0.0;
double y_train = 0.0;

long theta_laser_command_count = 0;
long phi_laser_command_count   = 0;

/********************************************
  Interrupt Handlers
*********************************************/

// highest-frequency clock
// #define TIMER_FREQ_HZ 240.0
#define TIMER_FREQ_HZ 80.0
// #define TIMER_FREQ_HZ 120.0
// hanldes the 80 Hz timer
bool HighFrequencyTimerHandler(void* timerNo)
{
  // Doing something here inside ISR
  counter_new_val_available = true;
  counter_80_hz++;
  return true;
}



/********************************************
  Communications
*********************************************/

#define ADC_BASE_ADDRESS    0x50 // 101 0000
#define ADC_RESULT_ADDRESS  0x00
#define ADC_CONFIG_ADDRESS  0x02

// set up ADC (no alert pin BUT need to float ADDR pin)
void init_ADC() {
  Serial.println("Initializing ADC...");
  // set CycleTime to 3'b001 (contained in D[7:5]), keep remaining bits 0
  // 8'b0010 0000 = 0x20
  I2C_16Bit_writeToModule(ADC_BASE_ADDRESS, ADC_CONFIG_ADDRESS, 0x20);
  uint16_t response = I2C_16Bit_readFromModule(ADC_BASE_ADDRESS, ADC_RESULT_ADDRESS);
  if (response != 0) {
    Serial.println("ADC initialized!");
  }
  else {
    Serial.println("ADC failed initialization!");
  }
}


// request information from the VB arduino
#define BIT_VBTA (0x01) // bit 1: vector board says train available
void request_arduino_comms() {
  // Serial.println("Requesting from arduino...");
  byte RxByte;
  Wire.requestFrom(0x87, 1); // Request from arduino @ 0x87, Data Length = 1Byte
  while(Wire.available()) {  // Read receive from arduino
    RxByte = Wire.read();
  }
  VB_train_available = (bool)(RxByte & BIT_VBTA);

  Serial.println("Got raw byte: " + String(RxByte));
}


/********************************************
  Helper Functions
*********************************************/

// service 60Hz PixyCam update
void loop_pixycam_update(){
  // // Serial.println("executed pixycam update, counter: " + String(counter_80_hz));


  if (inbound_message.pixy_saw_train) {
    inbound_message.pixy_saw_train = false;
    // smooth update
    const double alpha = 0.9;
    pixy_train_x = (alpha*inbound_message.pixy_train_x) + (1-alpha)*pixy_train_x;
    pixy_train_y = (alpha*inbound_message.pixy_train_y) + (1-alpha)*pixy_train_y;
    // reset watchdog
    PC_train_watchdog = 0;
    PC_train_found = true;
    // Serial.println("Found train!");
  }
  else { 
    pixy_train_x = (PIXY_MAX_X/2);
    pixy_train_y = (PIXY_MAX_Y/2);
    PC_train_watchdog++;
  }

  // compute location of train in global coordinates
  const double DELTA_X = 495.3; //mm
  const double DELTA_Y = 276.86;
  const double DELTA_Z = 248.92;
  const double h = 175.26;

  double theta_pixy_rad = 0.45*PI/180.0*track_yaw_params.count_est;
  double phi_pixy_rad   = 0.5625*PI/180.0*track_pitch_params.count_est;
  double d_range_proj = distance_train*cos(phi_pixy_rad);

  x_train = d_range_proj*sin(theta_pixy_rad);
  y_train = d_range_proj*cos(theta_pixy_rad);

  double x_laser = DELTA_Y - y_train;
  double y_laser = DELTA_X + x_train;

  double theta_laser_rad = atan2(x_laser, y_laser);
  double d_laser_proj = sqrt(x_laser*x_laser + y_laser*y_laser);

  double z_abs = h - distance_train*sin(phi_pixy_rad);
  double z_laser = z_abs - DELTA_Z;

  double phi_laser_rad = atan2(z_laser, d_laser_proj);

  theta_laser_command_count = (long)(180.0*theta_laser_rad/(0.45*PI));
  phi_laser_command_count   = (long)(180.0*phi_laser_rad /(0.5625*PI));

  if (counter_80_hz % 100 == 0) {
  // if (0) {
    // Serial.println("Position estimate: (" + String(x_train) + ", " + String(y_train) + ")");
    // Serial.println("Theta command:      " + String(theta_laser_command_count));
    Serial.println("Phi command:        " + String(phi_laser_command_count));
    Serial.println("Phi estimate:       " + String(target_pitch_params.count_est));
    Serial.println(" ");
  }
  
}


// service 60Hz rangefinder update
// DEPRECATED
void loop_rangefinder_update(){
  // Serial.println("executed rangefinder update, counter: " + String(counter_80_hz));

  if (inbound_message.rangefinder_got_range) {
    inbound_message.rangefinder_got_range = false;
    distance_train = inbound_message.rangefinder_range_mm;
  }
}

// reset PID parameters so motors don't go crazy
void reset_PID(PID_params* params) {
  params->integrator = 0.0;
  params->curr_error = 0.0;
  params->prior_error = 0.0;
}


// enable or disable all steppers
void enable_disable_steppers(bool enable) {
  if (enable) {
    track_yaw.enable();
    track_pitch.enable();
    target_yaw.enable();
    target_pitch.enable();
    steppers_enabled = true;
  }
  else {
    track_yaw.disable();
    track_pitch.disable();
    target_yaw.disable();
    target_pitch.disable();
    steppers_enabled = false;
  }
}
// Have the steppers search for the target by sweeping the straight lines of track from entry to exit
void search() {
  if (track_pitch_params.count_est != 0) {
    unwind_stepper(&track_pitch_params, &track_pitch);
  }
  sweep_steppers(&track_yaw_params, &track_yaw);
}


//sweep steppers to find target panning right and left in certain range, 
// until pixie cam sees the target
void sweep_steppers(PID_params* params, BasicStepperDriver* driver) {

  const long cw_sweep_limit = 200; // will be 7 steps to the right of home (105 counts)
  const long ccw_sweep_limit = -200; // will be 7 steps to the left of home (105 counts)
  
  long step_size = (sweep_ccw ? -15 : 15); // sweep in steps of 15 or more neg if ccw pos if cw

  if ((sweep_ccw && params->count_est < ccw_sweep_limit) || (!sweep_ccw && params->count_est > cw_sweep_limit)) {
    sweep_ccw = !sweep_ccw;
    step_size = -step_size; // reverse direction
  }
  driver->move(step_size);
  params->count_est += step_size;
}

// unwind if we hit -720 or 720 degrees
void unwind_stepper(PID_params* params, BasicStepperDriver* driver) {
  // Serial.println("Unwinding!");
  noInterrupts();
  long step_size = (params->count_est < 0) ? 15 : -15; // step slowly back to home


  while (abs(params->count_est) >= abs(step_size)) {
    driver->move(step_size);
    params->count_est += step_size;
    delay(30);
  }
  
  // step the rest of the way
  driver->move(-params->count_est);
  params->count_est = 0;

  interrupts();
}

// bring all steppers back to home
void home_steppers() {
  unwind_stepper(&target_pitch_params, &target_pitch);
  delay(100);
  unwind_stepper(&target_yaw_params, &target_yaw);
  delay(100);
  unwind_stepper(&track_pitch_params, &track_pitch);
  delay(100);
  unwind_stepper(&track_yaw_params, &track_yaw);
  delay(100);
}

// generic PID execution functions (can execute once for each stepper motor)
#define CONTROL_PERIOD (1.0 / TIMER_FREQ_HZ)
void execute_PID(PID_params* params, BasicStepperDriver* driver, int i) {
  // update integrator
  params->integrator += params->curr_error;
  if (params->integrator >= params->integrator_sat) {
    params->integrator = params->integrator_sat;
  }
  else if (params->integrator <= -params->integrator_sat) {
    params->integrator = -params->integrator_sat;
  }
  // PID lead out
  double command =  (params->kp * params->curr_error) 
                  + (params->kd * (params->curr_error - params->prior_error)/CONTROL_PERIOD) 
                  + (params->ki * params->integrator * CONTROL_PERIOD);
  // update priors and clip command
  params->prior_error = params->curr_error;
  if (command >= params->command_clip) {
    command = params->command_clip;
  }
  else if (command <= -params->command_clip) {
    command = -params->command_clip;
  }

  // bounds clipping
  long command_l = (long)command;
  if (params->count_est + command_l > params->count_clip || params->count_est + command_l < -params->count_clip) {
    Serial.println("Hit count limit: " + String(params->count_est));
    command_l = 0;
    if (params == &track_yaw_params) {
      unwind_stepper(params, driver);
    }
  }

  // issue command
  driver->move(command_l);
  params->count_est += command_l;
  
  if (i%10 == 0) {
    Serial.println("Executed PID loop, new params: ");
    Serial.println("\tError:      " + String(params->curr_error));
    Serial.println("\tLast Error: " + String(params->prior_error));
    Serial.println("\tIntegrator: " + String(params->integrator));
    Serial.println("\tCommand:    " + String(command_l));
    Serial.println("\tEstimate:   " + String(params->count_est));
  }
}

void move_laser_pointer() {

  long laser_delta_theta = theta_laser_command_count - target_yaw_params.count_est;

  if (laser_delta_theta >= target_yaw_params.command_clip) {
    laser_delta_theta = target_yaw_params.command_clip;
  }
  else if (laser_delta_theta <= -target_yaw_params.command_clip) {
    laser_delta_theta = -target_yaw_params.command_clip;
  }

  if (theta_laser_command_count > 230
    ||theta_laser_command_count < -230) {
    
    laser_delta_theta = 0;
    // unwind_stepper(&target_yaw_params, &target_yaw);
    Serial.println("Hit laser yaw clip: " + String(target_yaw_params.count_est));
  }
  target_yaw.move(laser_delta_theta);
  target_yaw_params.count_est += laser_delta_theta;

  long laser_delta_phi   = phi_laser_command_count - target_pitch_params.count_est;

  if (laser_delta_phi >= target_pitch_params.command_clip) {
    laser_delta_phi = target_pitch_params.command_clip;
  }
  else if (laser_delta_phi <= -target_pitch_params.command_clip) {
    laser_delta_phi = -target_pitch_params.command_clip;
  }

  if (phi_laser_command_count >  0 
    ||phi_laser_command_count < -120) {
    Serial.println("Hit laser pitch clip: " + String(target_pitch_params.count_est));
    laser_delta_phi = 0;
  }

  target_pitch.move(laser_delta_phi);
  target_pitch_params.count_est += laser_delta_phi;
}

// service 80Hz position loop updates and update state!
void loop_position_update(){
  // Serial.println("executed position update, counter: " + String(counter_80_hz));


  // check this watchdog first to make sure we have up-to-date control signals
  if (PC_train_watchdog >= PC_train_watchdog_max) {
    PC_train_found = false;
    PC_train_watchdog = PC_train_watchdog_max;
  }
  
  // update state
  State next_state = STATE_inactive;
  switch (control_state) {
    case STATE_inactive:
      if (!VB_train_available || EXT_kill) {
        next_state = STATE_inactive;
      }
      else if (VB_train_available) {
        next_state = STATE_search;
      }
      break;
    case STATE_search:
      if (!VB_train_available || EXT_kill) {
        next_state = STATE_inactive;
      }
      else if (!PC_train_found) {
        next_state = STATE_search;
      }
      else if (PC_train_found) {
        next_state = STATE_lock;
      }
      break;
    case STATE_lock:
      if (!VB_train_available || EXT_kill) {
        next_state = STATE_inactive;
      }
      else if (!PC_train_found) {
        next_state = STATE_search;
      }
      else if (PC_train_found) {
        next_state = STATE_lock;
      }
      break;
  }
  
  control_state = next_state;


  // execute control calculations
  switch (control_state) {
    case STATE_inactive:
      digitalWrite(P_laser_on, LOW);
      if (steppers_enabled) {
        home_steppers();
        enable_disable_steppers(false);
      }
      break;
    case STATE_search:
      digitalWrite(P_laser_on, LOW);
      if (!steppers_enabled) {
        enable_disable_steppers(true);
      }
      search();
      break;
    case STATE_lock: 
      if (!steppers_enabled) {
        enable_disable_steppers(true);
      }
      digitalWrite(P_laser_on, HIGH);
      track_yaw_params.curr_error =   ((PIXY_MAX_X/2.0) - pixy_train_x);
      track_pitch_params.curr_error = ((PIXY_MAX_Y/2.0) - pixy_train_y);
      execute_PID(&track_yaw_params, &track_yaw, 1);
      execute_PID(&track_pitch_params, &track_pitch, 1);
      break;
  }



  // laser pointer control update
}



/********************************************
  Setup and Loop
*********************************************/

#include "mae412_group5_utests.h"
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
void loop() {
  // put your main code here, to run repeatedly:


  if (counter_new_val_available) {
    counter_new_val_available = false;  // clear flag!!!!

    // important: get kill switch first! Kill when the switch is OFF
    EXT_kill = !digitalRead(P_kill_switch);

    // handle pixycam and rangefinder updates at correct phases
    switch (counter_80_hz % 4) {
      case 0:
        loop_pixycam_update();
        break;
      case 1:
        break;
      case 2:
        loop_rangefinder_update();
        break;
      case 3:
        request_arduino_comms();
        if (control_state == STATE_lock) {
          move_laser_pointer();
        }
        break;
    }

    // enforce ESP-NOW watchdog
    #define WIFI_WATCHDOG_MAX 20
    wifi_watchdog++;
    if (wifi_watchdog > WIFI_WATCHDOG_MAX) {
      // Serial.println("Lost ESP-NOW connection!");
      // reset all control signals so we don't do anything stupid
      reset_PID(&track_pitch_params);
      reset_PID(&track_yaw_params);
      // reset_PID(&target_pitch_params);
      // reset_PID(&target_yaw_params);
      wifi_watchdog = WIFI_WATCHDOG_MAX; // don't let it overflow
    }
    else {
      // always execute position loops
      loop_position_update();
    }

    if (counter_80_hz % 50 == 0) {
      String state_string = (control_state == STATE_inactive) ? "inactive" :
                            (control_state == STATE_search)   ? "search"   :
                            (control_state == STATE_lock)     ? "lock"     : "bad state";
      // Serial.println("========\nSTATE: " + state_string + "\n========");

    }
  }
}

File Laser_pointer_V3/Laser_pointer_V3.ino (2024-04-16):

// JJROBOTS Two Axis.
// Author: Jose Julio & Juan pedro & Jonathan (JJROBOTS)
// Hardware: New JJROBOTS DEVIA M0 Board with Arduino M0 & ESP8266
// Date: 13/02/2018
// Last updated: 218/04/2020
// Version: 0.1
// Project page : http://jjrobots.com/
// License: Open Software GPL License v2

// Hardware: JJROBOTS DEVIA M0 board
// Board: Arduino/Genuine Zero (Native USB Port)

// Motor1:
// Enable: Arduino pin D11 (PA16)
// Step: Arduino pin 5 (PA15)
// Dir: Arduino pin 6 (PA20)

// Motor2:
// Enable: Arduino pin D11 (PA16)
// Step: Arduino pin 7 (PA21)
// Dir: Arduino pin 8 (PA06)

// Mircrostepping : Arduino pin A4 (PA05) (default 1/16)

#define VERSION "Scara v0.16"
//#define DEBUG 0

// ROBOT and USER configuration parameters
#include "Configuration.h"
#include <Servo.h>
#include <Wire.h>

Servo servo1; // Servo1
Servo servo2; // Servo2

// Configuration: Pins, servos, Steppers, Wifi...
void setup()
{
  // STEPPER PINS ON JJROBOTS DEVIA M0 BOARD
  pinMode(11, OUTPUT); // ENABLE MOTORS   ATSAMD21:PA16
  pinMode(5, OUTPUT); // STEP MOTOR 1 ATSAMD21:PA15
  pinMode(6, OUTPUT); // DIR MOTOR 1  ATSAMD21:PA20
  pinMode(7, OUTPUT); // STEP MOTOR 2 ATSAMD21:PA21
  pinMode(8, OUTPUT); // DIR MOTOR 2  ATSAMD21:PA06
  pinMode(9, OUTPUT); // STEP MOTOR 3 ATSAMD21:PA07
  pinMode(10, OUTPUT); // DIR MOTOR 3  ATSAMD21:PA18

  pinMode(A4, OUTPUT);    // Microstepping output
  digitalWrite(A4, HIGH); // 1/16 (default config)

  // Servos
  pinMode(3, OUTPUT); // SERVO1  ATSAMD21:PA09
  pinMode(4, OUTPUT); // SERVO2  ATSAMD21:PA08

  pinMode(12, OUTPUT); // Electromagnet output (PA19) [optional]
  digitalWrite(12, LOW); //Disabled

  pinMode(RED_LED, OUTPUT); // RED LED
  pinMode(GREEN_LED, OUTPUT); // GREEN LED
  pinMode(SWITCH_IN, INPUT_PULLUP);  // Input Switch
  digitalWrite(SWITCH_IN, OUTPUT); // PULLUP

  digitalWrite(11, HIGH);  // Disbale stepper motors
  digitalWrite(RED_LED, HIGH);  // RED LED ON

  // Serial ports initialization
  delay(100);
  SerialUSB.begin(115200); // Serial output to console
  Serial1.begin(115200); // Wifi initialization
  Wire.begin();
  delay(1000);

#ifdef DEBUG
  delay(10000);  // Only needed for serial debug
  SerialUSB.println(VERSION);
#endif

  // WIFI MODULE INITIALIZATION PROCESS
  SerialUSB.println("WIFI init");
  Serial1.flush();
  Serial1.print("+++");  // To ensure we exit the transparent transmision mode
  delay(100);

  ESPsendCommand(String("AT"), String("OK"), 1);
  //ESPsendCommand(String("AT+RST"), String("OK"), 2); // ESP Wifi module RESET
  //ESPwait(String("ready"), 6);
  ESPsendCommand(String("AT+GMR"), String("OK"), 5);

  Serial1.println("AT+CIPSTAMAC?");
  ESPgetMac();
  SerialUSB.print("MAC:");
  SerialUSB.println(MAC);
  delay(100);
  ESPsendCommand(String("AT+CWMODE=2"), String("OK"), 3); // Soft AP mode
  //SerialUSB.println("Aqui tambien");
  // Generate Soft AP. SSID=JJROBOTS_XX (XX= user MAC last characters), PASS=87654321
  String cmd =  String("AT+CWSAP=\"JJROBOTS_") + MAC.substring(MAC.length() - 2, MAC.length()) + String("\",\"87654321\",5,3");
  ESPsendCommand(cmd, String("OK"), 6);

  // Start UDP SERVER on port 2222, telemetry port 2223
  SerialUSB.println("Start UDP server");
  ESPsendCommand(String("AT+CIPMUX=0"), String("OK"), 3);  // Single connection mode
  delay(10);
  ESPsendCommand(String("AT+CIPMODE=1"), String("OK"), 3); // Transparent mode
  delay(10);
  String Telemetry = String("AT+CIPSTART=\"UDP\",\"") + String(TELEMETRY) + String("\",2223,2222,0");
  ESPsendCommand(Telemetry, String("CONNECT"), 3);
  SerialUSB.println(Telemetry);
  delay(200);
  ESPsendCommand(String("AT+CIPSEND"), String('>'), 2); // Start transmission (transparent mode)

  // Start TCP SERVER on port 2222, telemetry port 2223
  //SerialUSB.println("Start TCP server");
  //ESPsendCommand("AT+CIPCLOSE=0","OK",3);
  //ESPsendCommand("AT+CIPSERVER=0","OK",3);
  //ESPsendCommand("AT+CIPMUX=1", "OK", 3);  // Multiple connection mode
  //ESPsendCommand("AT+CIPMODE=1", "OK", 3); // Transparent mode
  //ESPsendCommand("AT+CIPSERVER=1,2222", "OK", 3); // TCP server
  delay(100);

  // Init servos
  initServo();
  moveServo1(SERVO1_NEUTRAL);
  moveServo2(SERVO2_NEUTRAL);

  // Debug: Output parameters
  //SerialUSB.print("Max_acceleration_x: ");
  //SerialUSB.println(acceleration_x);
  //SerialUSB.print("Max_acceleration_y: ");
  //SerialUSB.println(acceleration_y);
  //SerialUSB.print("Max speed X: ");
  //SerialUSB.println(MAX_SPEED_X);
  //SerialUSB.print("Max speed Y: ");
  //SerialUSB.println(MAX_SPEED_Y);

  // STEPPER MOTORS INITIALIZATION
  SerialUSB.println("Steper motors initialization...");
  SerialUSB.print("Motor1 AXIS per STEP unit:");
  SerialUSB.println(M1_AXIS_STEPS_PER_UNIT);
  SerialUSB.print("Motor2 AXIS per STEP unit:");
  SerialUSB.println(M2_AXIS_STEPS_PER_UNIT);
  
  timersConfigure();
  SerialUSB.println("Timers initialized");
  timersStart(); //starts the timers
  SerialUSB.println("Timers started");
  delay(100);
  SerialUSB.println("Moving to initial position...");

  //Initializing init position
  target_angleA1 = ROBOT_INITIAL_POSITION_M1;
  target_angleA2 = ROBOT_INITIAL_POSITION_M2;
  position_M1 = target_angleA1 * M1_AXIS_STEPS_PER_UNIT;
  position_M2 = target_angleA2 * M2_AXIS_STEPS_PER_UNIT;

  //target_angleA1 = ROBOT_INITIAL_POSITION_M1;
  //target_angleA2 = ROBOT_INITIAL_POSITION_M2 + ROBOT_INITIAL_POSITION_M1*AXIS2_AXIS1_correction;

  configSpeed(MAX_SPEED_M1, MAX_SPEED_M2);
  configAcceleration(MAX_ACCEL_M1, MAX_ACCEL_M2);
  setSpeedAcc();
  target_position_M1 = position_M1;
  target_position_M2 = position_M2;

  SerialUSB.println("Initial position configured!");
 
  SerialUSB.println(" Ready...");
  SerialUSB.print(" JJROBOTS 2 Axis platform ");
  SerialUSB.println(VERSION);
  timer_old = micros();
  slow_timer_old = millis();
  laser_timer_old = millis();
  timeout_counter = 0;

  digitalWrite(RED_LED, LOW);  // RED LED OFF
  digitalWrite(GREEN_LED, HIGH);  // GREEN LED ON

  // Enable motors
  digitalWrite(11, LOW);  // Enable motors
}
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

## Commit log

2024-04-06 start I2C comms, ADC config, Pixy config
    Untested!
2024-04-07 add pinout information, fix a unit test
    [mae412_group5.ino]
2024-04-09 Tested pixycam, watchdog timer for getBlocks()
2024-04-15 New distance sensor integrated, but pixy probs
2024-04-16 add example laser pointer code
    [Configuration.h]
2024-04-20 New defines for stepper motors
2024-04-20 Add stepper driver initialization
2024-04-20 Initialize PID params (dummy values)
2024-04-21 (untested) PID skeleton, code cleanup
2024-04-23 PID execution unit testing
2024-04-25 start tuning PID
2024-04-29 GOOD PID PARAMETERS HERE!!!!!!
2024-05-03 convert timer infrastructure to ESP32
2024-05-03 testing for open-loop positioning of servos
2024-05-03 WIRELESS TRACKING
2024-05-04 I2C ESP<->Mini (soon to be vector board arduino)
2024-05-04 configure vector board arduino for ACIA serial
2024-05-04 Add encoder count estimate
2024-05-04 Homing functionality
    Updating pin definitions in VB arduino
2024-05-04 gate PID execution on control_state
2024-05-05 Defines for hall effect and switching
2024-05-05 Smart enable/disable of steppers
2024-05-05 Integrate kill switch
2024-05-05 implement switch-throwing state machine
2024-05-05 Add thresholding+hysteresis to hall effect
2024-05-07 initialize and disable motors right away
2024-05-08 i2c working between vector board arduino
2024-05-08 first draft incorporating laser pointer
2024-05-08 New motor enable pinout
2024-05-09 EAGLE, Fusion, AnyRail, Vector, GAL
    CAD and code files for project
    [12v_power_supply_v10.brd, BASE_V10.stl, CAP_V10.stl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]
2024-05-13 rebounded and changed when laser movement happens
2024-05-14 turn laser off first thing!
2024-05-15 240->80 Hz
2024-05-15 update arduino comms request
2024-05-15 fix VIA handling bug
    [mae412_group5_vb_arduino.ino]

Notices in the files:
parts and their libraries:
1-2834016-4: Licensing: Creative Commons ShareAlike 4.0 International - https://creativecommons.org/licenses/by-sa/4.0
